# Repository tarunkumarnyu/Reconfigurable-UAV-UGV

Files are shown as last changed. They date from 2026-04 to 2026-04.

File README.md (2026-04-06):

# Reconfigurable UAV + UGV





> **Design project.** This repository documents the mechanical design, sizing, structural analysis, and electronics architecture of the vehicle. It is a CAD + analysis effort, not a software stack.

A hybrid robot that morphs between **quadrotor (UAV)** and **two-wheeled rover (UGV)** modes — inspired by the CalTech M4 Morphbot. The vehicle flies to a search location for rapid response, then transitions to ground mode in cluttered terrain to gain manoeuvrability and dramatically cut power consumption (dynamically stable → statically stable).

Targeted at search-and-rescue missions where pure ground robots get stuck and pure quadrotors burn through battery hovering.

## Demo

https://github.com/user-attachments/assets/98f587c6-136c-463c-a7f6-8aad75f0b5d4

## Configurations

<p align="center">
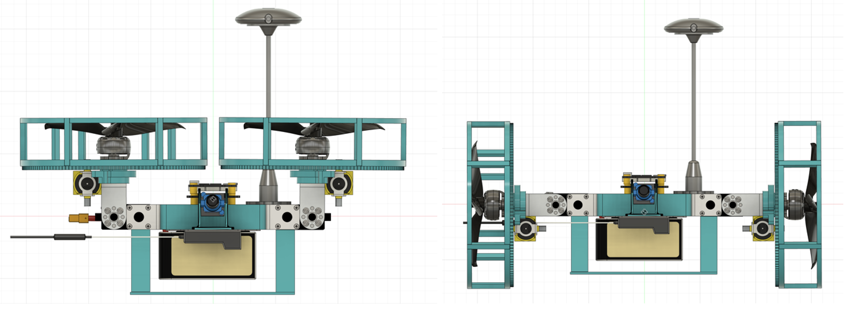
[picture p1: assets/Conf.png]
UAV and UGV configurations
  
</p>

| Mode | Actuators | When it's used |
|---|---|---|
| **UAV** | 4× BLDC motors | Long-distance traversal, gap-crossing, rapid deployment to a waypoint |
| **UGV** | 2× DC motors driving the wheels through a 1:10 gear ring | Cluttered indoor / collapsed-structure search where flight is unsafe or wasteful |
| **Reconfiguration** | 2× servos rotating the motor-arm assemblies | Switches between modes in place |

Total of **8 actuators**: 4 BLDC + 2 DC + 2 servos.

## Specifications

| | |
|---|---|
| Take-off weight | 1134 g |
| Thrust per motor | 340.2 g (≈1.2× hover thrust) |
| Power required | 31.08 Wh |
| Estimated endurance | 4.21 min (UAV mode) |
| Payload limit | 100 g |
| Length × height | 310 mm × 230 mm |
| Wheelbase (motor mount, diagonal) | 225 mm |
| Wheel diameter | 150 mm |
| Propeller clearance | 33 mm |
| Landing-gear height | 50 mm (15 mm ground clearance in UGV mode) |

<p align="center">
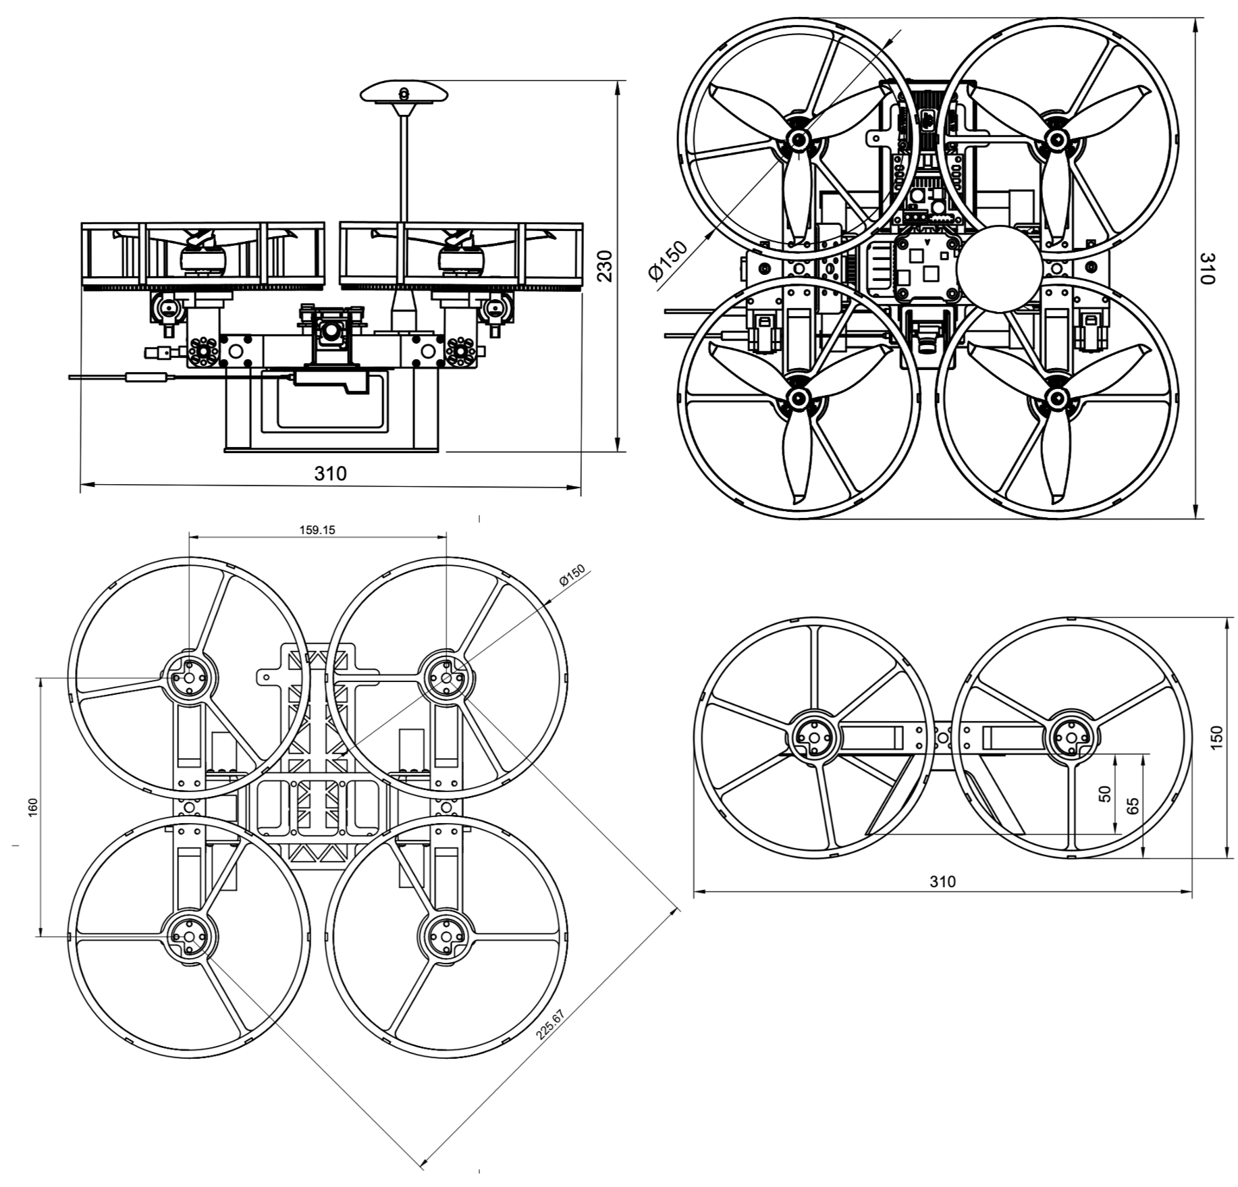
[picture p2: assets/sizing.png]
Dimensions and sizing
  
</p>

<p align="center">
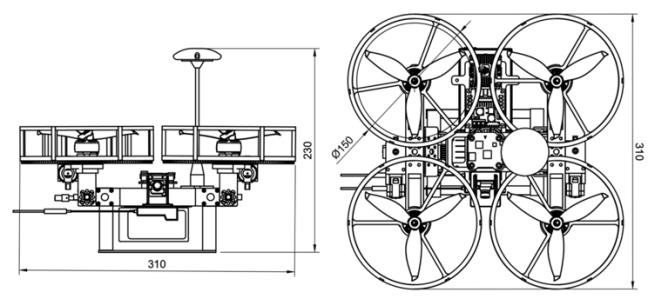
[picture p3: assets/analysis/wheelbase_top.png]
Top view — wheelbase and propeller clearance
  
</p>

## Sizing & Power Budget

The vehicle was sized from a target take-off weight, then back-solved through thrust, power, and endurance.

**Weight estimation.**

```
W_to = W_oe + W_pl + W_f
W_oe = 345 g (frame) + 630 g (electronics, no battery) = 975 g
W_f  = 225 g (battery, treated as fuel weight)
W_to = 975 + 225 = 1200 g
```

**Thrust estimation.** Hover requires thrust = weight; we add a 20 % margin for control authority.

```
T_required = 1.2 × 1200 g = 1440 g
T_per_motor = 1440 / 4 = 360 g
```

**Power estimation.** From a test-stand measurement at hover thrust per motor: 3.5 A @ 25.2 V → 88.2 W per motor.

```
P_motors = 4 × 88.2 W = 352.8 W
P_avionics ≈ 20 W
P_total ≈ 373 W
E_5min  = 373 W × (5/60) h = 31.08 Wh
```

**Battery selection.** A **6S 1300 mAh 150C LiPo** delivers 1.3 Ah × 25.2 V = **32.76 Wh**, leaving a small margin over the 31.08 Wh budget.

**Endurance** (capping discharge at 80 % to protect the LiPo):

```
P/W   = 373 / 1.2 ≈ 310.83 W/kg
I_avg = (1.2 × 310.83) / 25.2 ≈ 14.80 A
t     = (1.3 Ah × 0.8) / 14.80 A ≈ 0.0703 h ≈ 4.22 min
```

The 4.22 min UAV endurance is the **worst case** (continuous hover). UGV mode draws an order of magnitude less because the platform is statically stable on its wheels — this is the entire reason for the hybrid design.

## System Architecture

<p align="center">
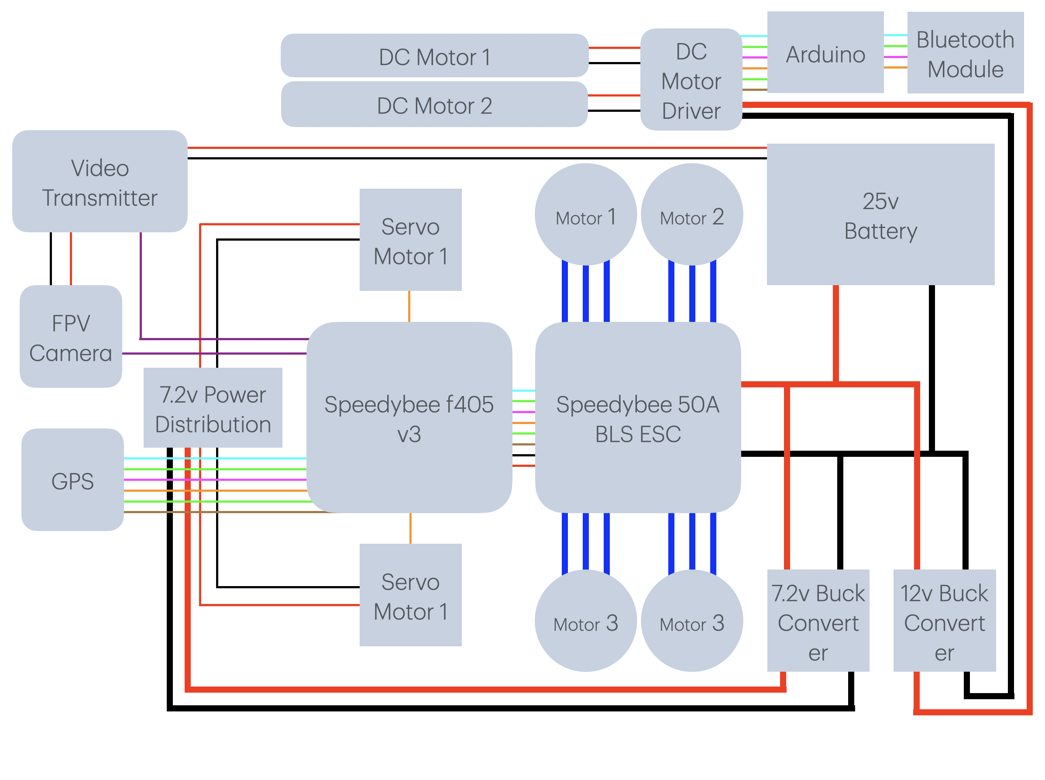
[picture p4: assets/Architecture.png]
Electrical / control architecture
  
</p>

**Flight controller.** STM32F405 ARM microcontroller with 6× UART for peripherals. Runs the UAV control loop and routes commands during reconfiguration.

**Ground controller.** Separate ATmega328-based board drives the H-bridge for the DC wheel motors in UGV mode — keeps the high-current ground drive isolated from the flight controller.

**Sensing.**
- **DPS310 barometer** — altitude hold.
- **Ublox NEO-M8N GPS** — 0.6–0.9 m position accuracy, on FC UART6 for waypoint navigation.
- **Compass** — heading reference for waypoint following, on I²C.
- **2.4 GHz SBUS receiver** — manual override, on UART2.

**FPV.** 1200 TVL 5 MP camera + 5.8 GHz video transmitter streaming live to the ground station's FPV display.

**ESCs.** 4-in-1 integrated 55 A ESC — single board for all four BLDC motors, total weight 15 g.

**Power tree.**
- 6S 1350 mAh Li-ion → 25.2 V → 4-in-1 ESC (BLDCs)
- LM2596S buck → 12 V → H-bridge → DC wheel motors
- XL4005 buck → 7.2 V @ 5 A → reconfiguration servos

## Structural Design

The frame has three structural sub-assemblies: **central body**, **motor-mount beams**, and **wheels**. Most parts are 3D printed in PLA+; the central chassis plate is **carbon fibre** for stiffness and weight.

**Central body.** Houses the flight controller, ATmega ground controller, ESCs, receiver, and battery. The battery sits at the geometric centre to keep CG aligned for both flight and ground modes.

**Motor-mount beams.** Run parallel to the central body on each side and pivot on the reconfiguration servos. They carry the BLDC motors in flight mode and become the rolling axle in ground mode. Mounting holes integrate a bearing seat to hold the wheel inner race.

<p align="center">
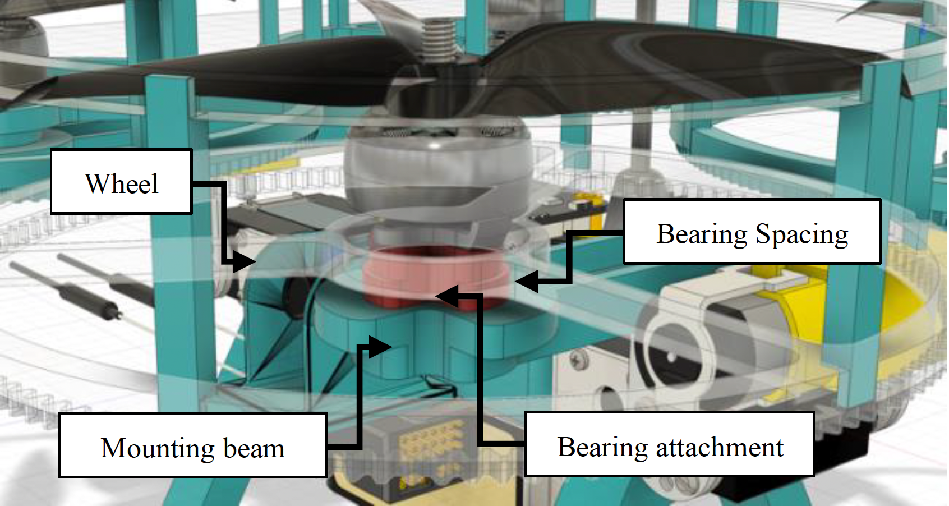
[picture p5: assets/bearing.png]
Bearing attachment detail
  
</p>

**Wheels.** Each wheel turns on a bearing to eliminate axle friction during ground motion. Both wheels are driven by a single DC motor through a common ring gear, so the wheels themselves are printed with **integrated gear teeth on the outer circumference** giving a **1:10 gear ratio** — high torque for climbing obstacles, in trade for top speed. The wheel webs are **topology-optimised** to remove material while preserving stiffness, also reducing aerodynamic drag in flight mode.

<p align="center">
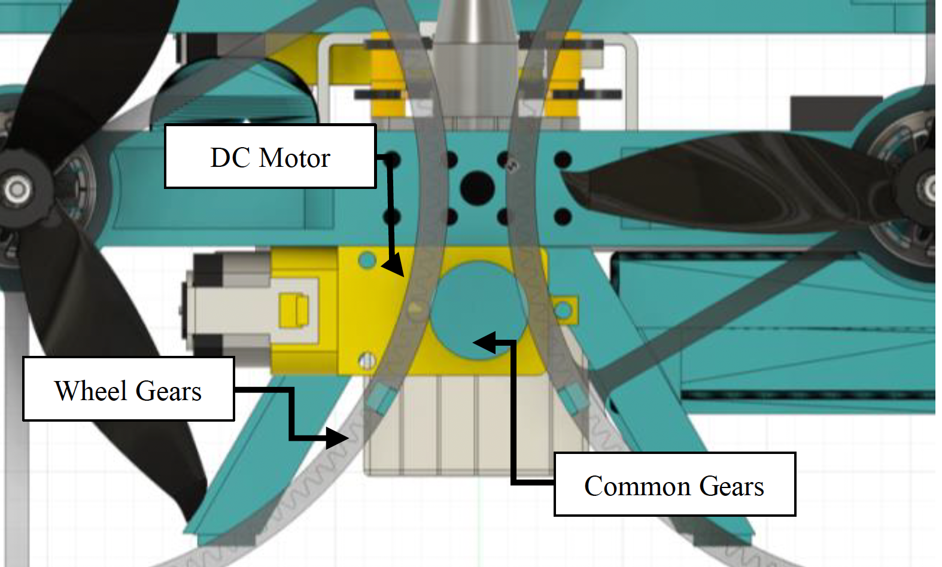
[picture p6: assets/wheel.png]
Wheel with integrated gear teeth
  
  &nbsp;
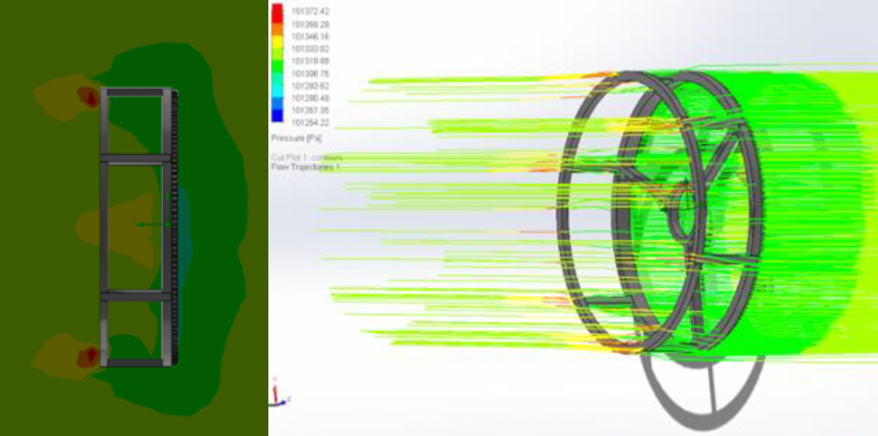
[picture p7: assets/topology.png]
Topology optimisation result
  
</p>

<p align="center">
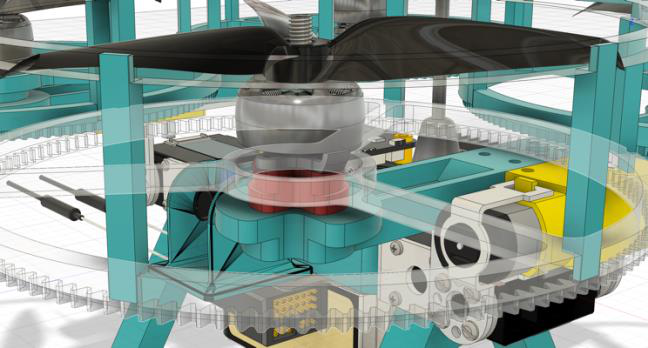
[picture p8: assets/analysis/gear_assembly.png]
Wheel gears, DC motor, common gear assembly
  
</p>

## Centre of Gravity

The CG is held close to the geometric centre of the frame by anchoring the battery (the heaviest single item) to the bottom of the central body. There is a deliberate **CG shift between modes**:

- **UAV mode** — CG is ~5 mm above the top of the central structure.
- **UGV mode** — CG is ~2 mm above the bottom of the central structure.

The two CG positions differ by ~23 mm (20 mm of which is the central plate thickness). In flight that puts the CG slightly *above* the rotor plane for predictable handling; on the ground it sits *below* the wheel axles, giving a low static stability margin against tipping.

<p align="center">
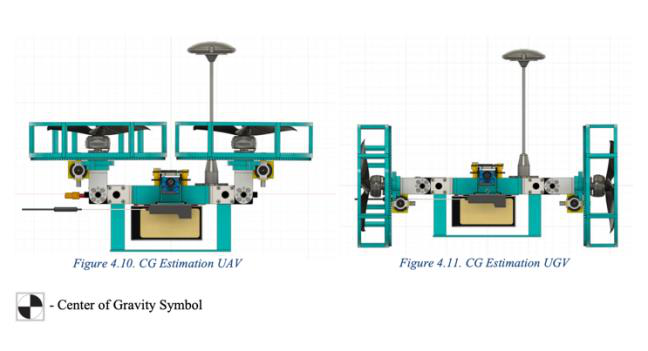
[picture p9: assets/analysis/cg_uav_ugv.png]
CG estimation in UAV and UGV modes
  
</p>

## Structural Analysis (FEA)

Static structural analysis was run in **Autodesk Fusion 360 Simulation** on the load-bearing parts. Loads are taken from worst-case flight forces (per-motor thrust + dynamic factor).

**Motor-arm beam.** Fixed at the centre (servo mount) with **20 N applied at each BLDC mounting hole**. Maximum von Mises stress is **5.742 MPa**, located between the servo and the BLDC mount — the expected stress concentration where the arm transitions from the servo coupling to the motor cantilever.

<p align="center">
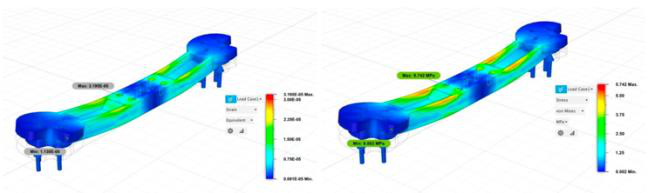
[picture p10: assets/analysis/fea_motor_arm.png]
Motor arm beam FEA — max 5.742 MPa
  
</p>

**Central structure (servo rear mount).** Fixed at the flight-controller mounting holes with **40 N per side** at the servo mounting holes (each side carries two BLDC motors at 20 N each). Maximum stress is **0.5 MPa** — a very high factor of safety, deliberately so since this part holds the entire reconfiguration mechanism.

<p align="center">
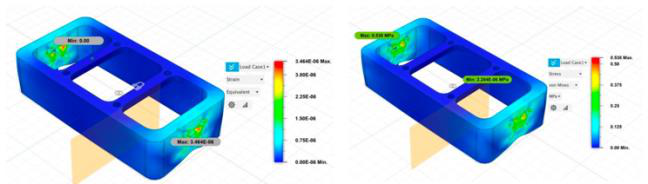
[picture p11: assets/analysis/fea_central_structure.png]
Central structure FEA — max 0.5 MPa
  
</p>

**Landing gear.** Skid type, chosen for stability and ground-contact area. Topology-optimised under landing-load constraints to maximise strength-to-weight. Maximum stress in the optimised geometry is **0.6 MPa**.

<p align="center">
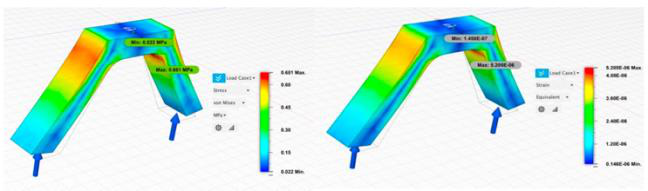
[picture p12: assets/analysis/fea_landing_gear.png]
Landing gear FEA — max 0.6 MPa
  
</p>

The landing-gear height (50 mm) is also constrained to be **smaller than the outer wheel radius**, so it never touches the ground in UGV mode — a 15 mm clearance is maintained throughout ground motion.

## Aerodynamics — Wheel Drag

Because the wheels stay on the airframe in UAV mode, their cross-section adds parasitic drag. Streamline analysis on the topology-optimised wheel shows the gear-tooth ring acts as a (mild) bluff body but the open spoke pattern lets most of the flow through, which was the goal of the optimisation:

<p align="center">
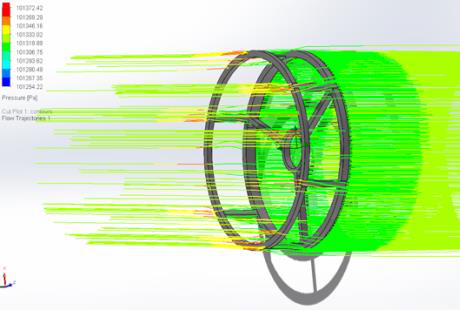
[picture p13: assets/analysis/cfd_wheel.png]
Streamline visualisation over the wheel
  
</p>

## Why a hybrid platform

A pure quadrotor wastes energy hovering and is unsafe near survivors and rubble. A pure ground robot can't cross gaps, climb collapsed slabs, or be deployed quickly across a wide search area. The reconfigurable approach uses each mode where it's actually efficient:

- **Fly** to the search zone — fast, terrain-independent.
- **Drive** inside the zone — orders-of-magnitude longer endurance, safer around people, and the static-stability margin means the vehicle can sit still without burning power.

## Status

Built, flown, and ground-driven. Reconfiguration is mechanical (servo-driven), GPS waypoint navigation works in UAV mode, and the FPV link feeds the ground station for manual operation in either mode.

## Credits

Concept inspired by the CalTech **M4 Morphbot**. Mechanical design, electronics integration, and bring-up by Tarunkumar Palanivelan.

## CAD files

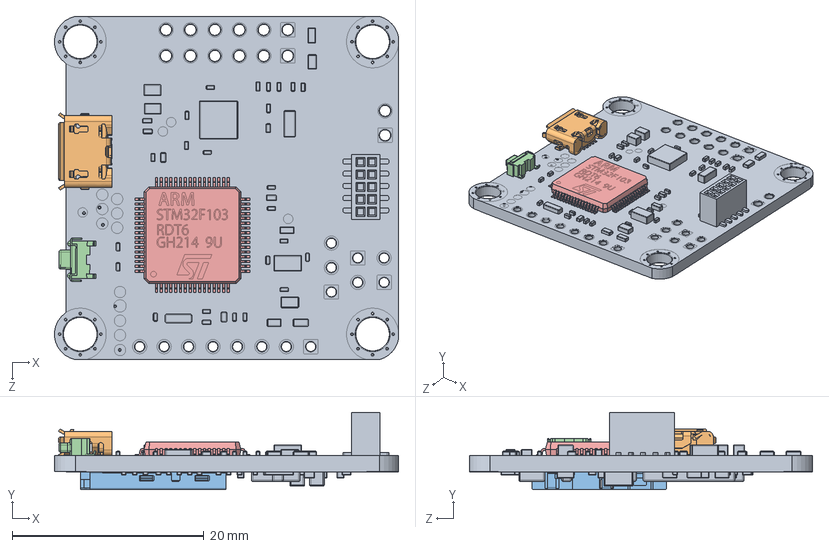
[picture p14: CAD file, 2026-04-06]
cad/Hobbywing Xrotor F4 FC.SLDASM
35.9 x 8.05 x 35.8 mm
MOTHER BOARD
USB port
microSD slot
Tact SMD Corner SWITRONIC IT-1100
STM32F103RDT6

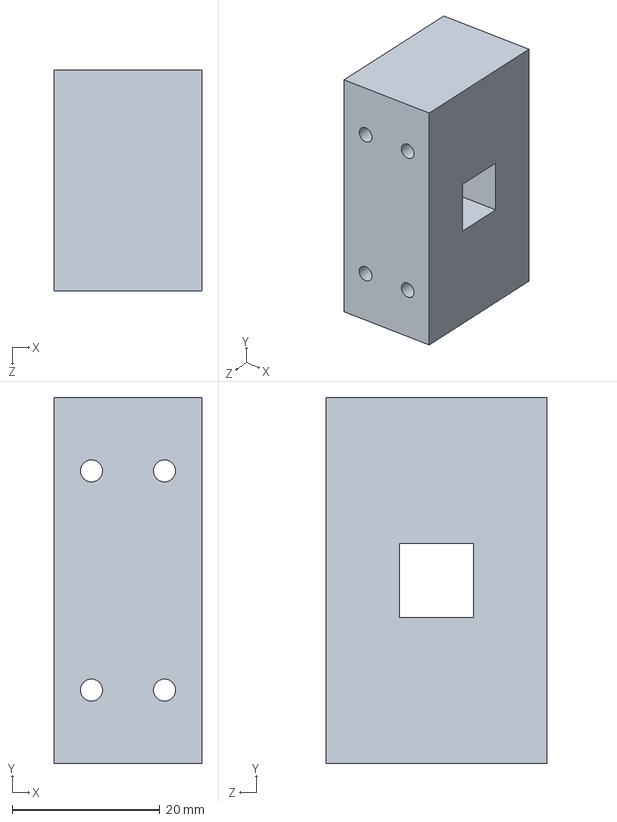
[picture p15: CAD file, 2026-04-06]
cad/Spacer_Block.SLDPRT
20.0 x 49.6 x 30.0 mm

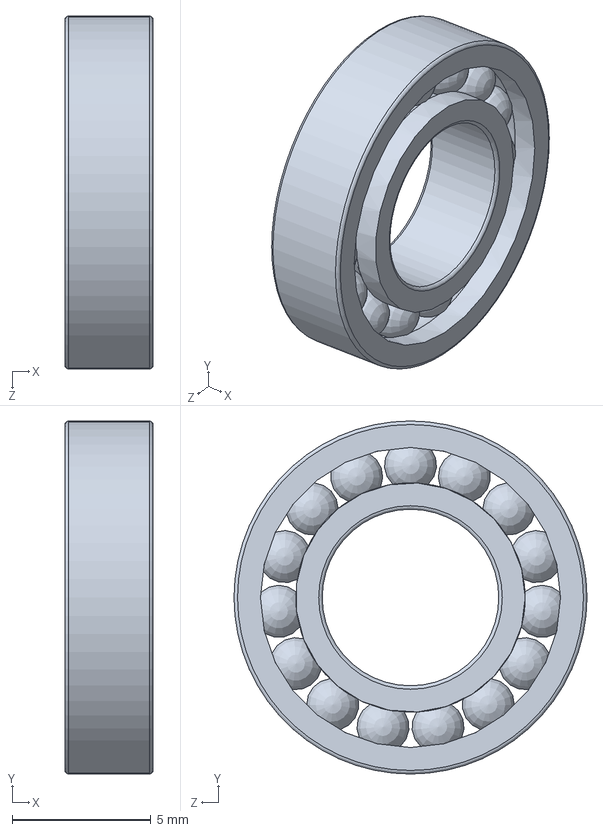
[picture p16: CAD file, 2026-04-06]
cad/instrument ball bearing_68_am.sldprt
3.17 x 12.7 x 12.7 mm

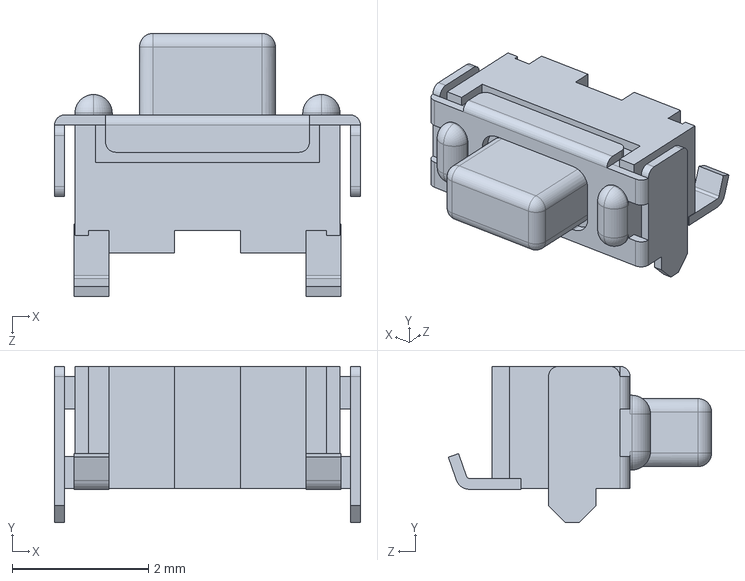
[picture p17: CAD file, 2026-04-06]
cad/Tact SMD Corner SWITRONIC IT-1100.SLDPRT
4.50 x 2.30 x 3.87 mm

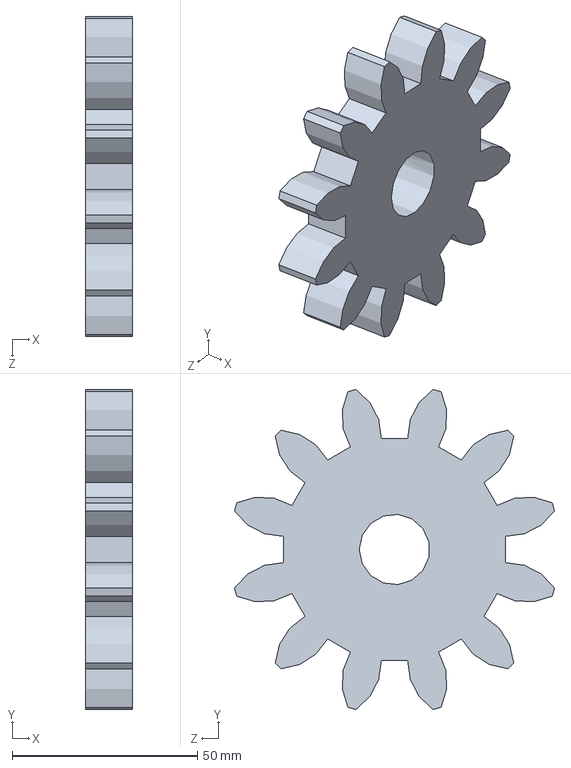
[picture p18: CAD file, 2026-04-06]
cad/spur gear wheel.SLDPRT
12.7 x 86.4 x 86.4 mm

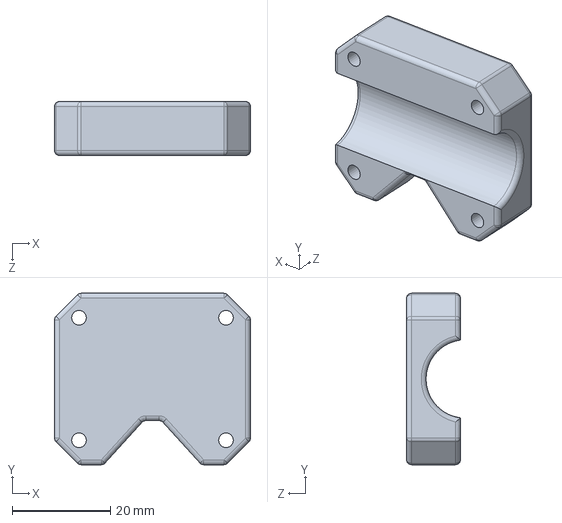
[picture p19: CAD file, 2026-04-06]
cad/bo_mountv3back.SLDPRT
40.0 x 35.0 x 11.0 mm

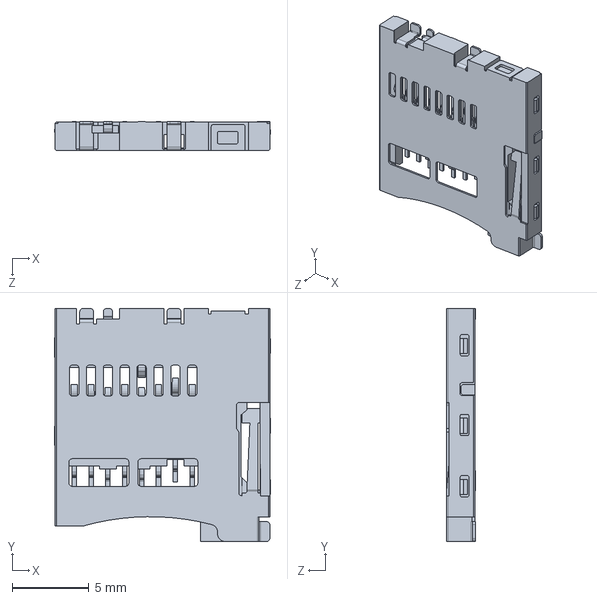
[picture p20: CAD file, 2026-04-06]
cad/microSD slot.SLDPRT
14.1 x 15.2 x 1.88 mm

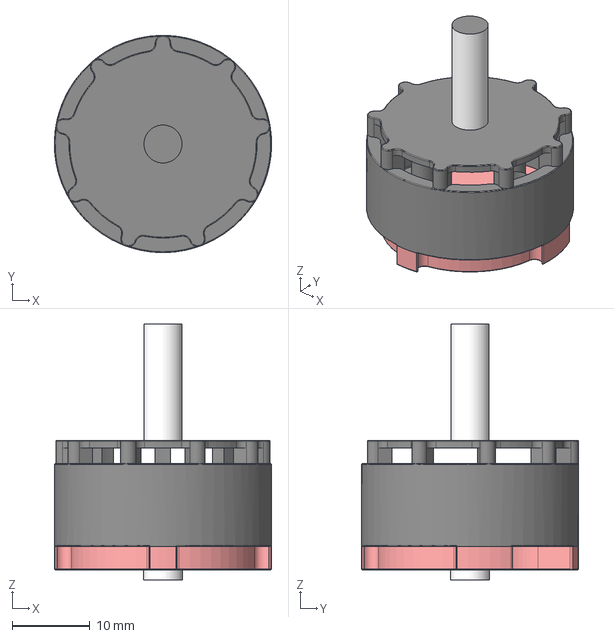
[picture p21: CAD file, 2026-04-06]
cad/Emax Rs2205 v1.step
28.0 x 28.0 x 33.0 mm

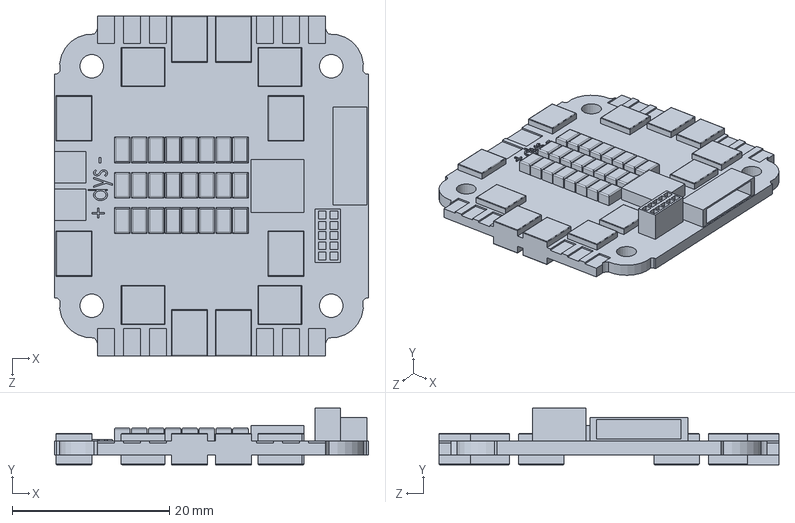
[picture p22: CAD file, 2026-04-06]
cad/DYSf30A_4in1_ESC_Coloured.SLDPRT
40.0 x 7.20 x 43.3 mm

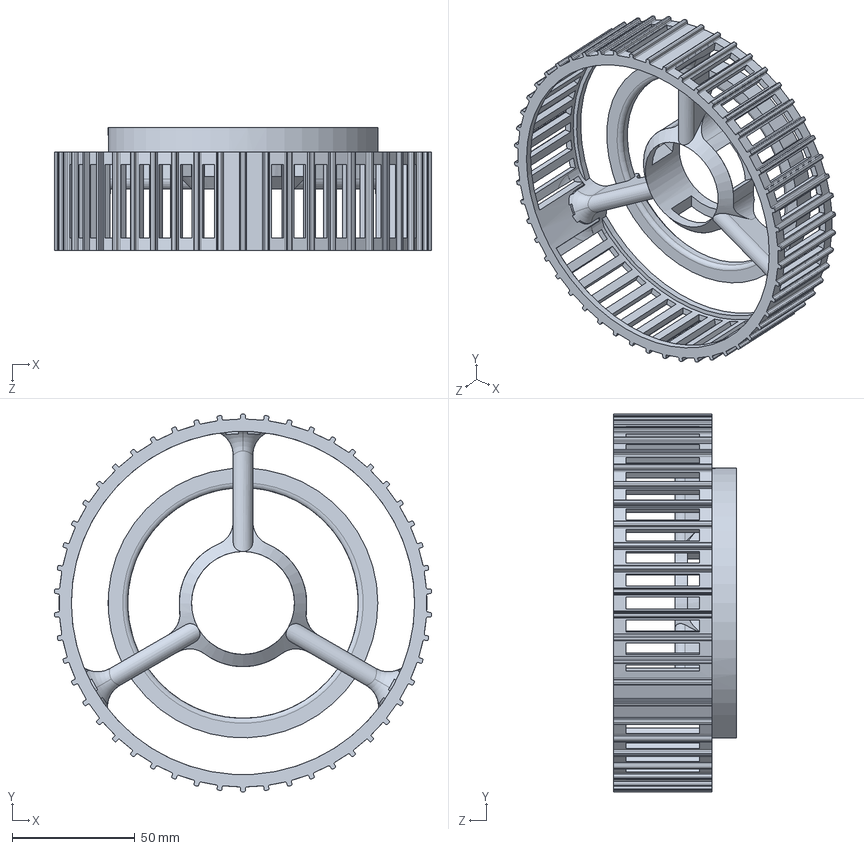
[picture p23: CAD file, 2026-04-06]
cad/wheel.SLDPRT
153.8 x 154.0 x 50.0 mm

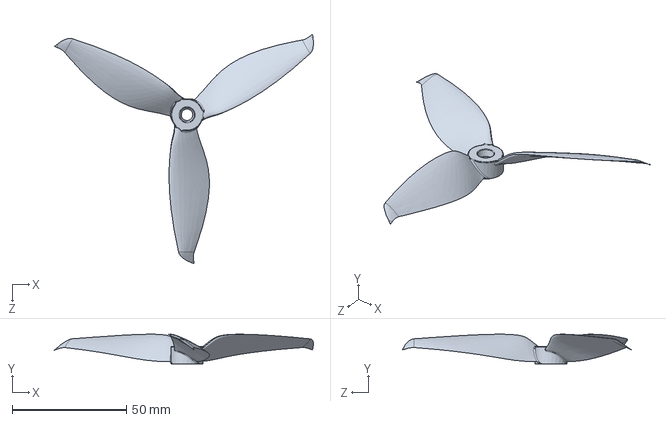
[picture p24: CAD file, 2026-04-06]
cad/GEMFAN_5152_CW.SLDPRT
113.3 x 12.9 x 100.5 mm

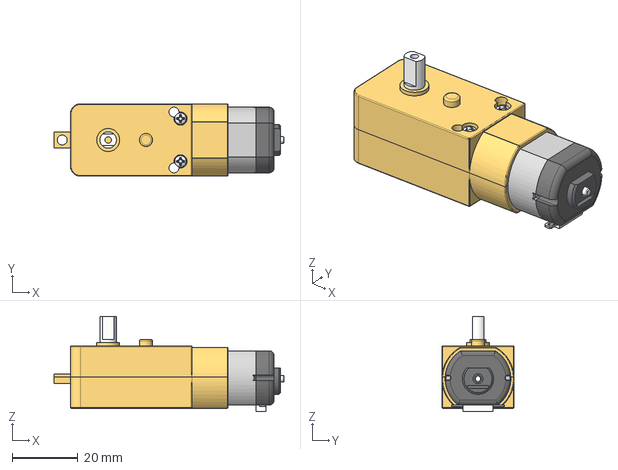
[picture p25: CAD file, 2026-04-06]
cad/One side TT Motor v1.step
70.0 x 22.0 x 29.0 mm

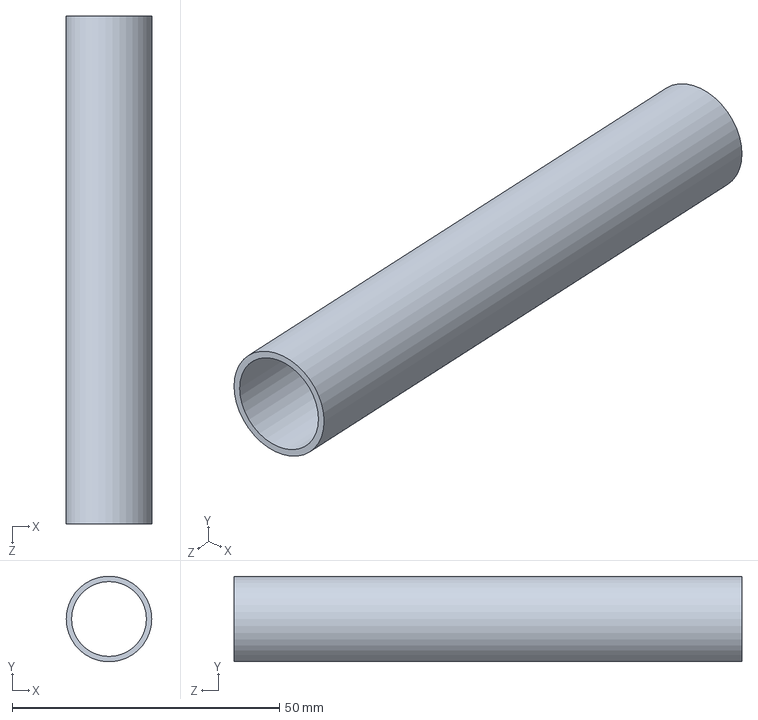
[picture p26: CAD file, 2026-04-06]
cad/95rod.SLDPRT
16.0 x 15.9 x 95.0 mm

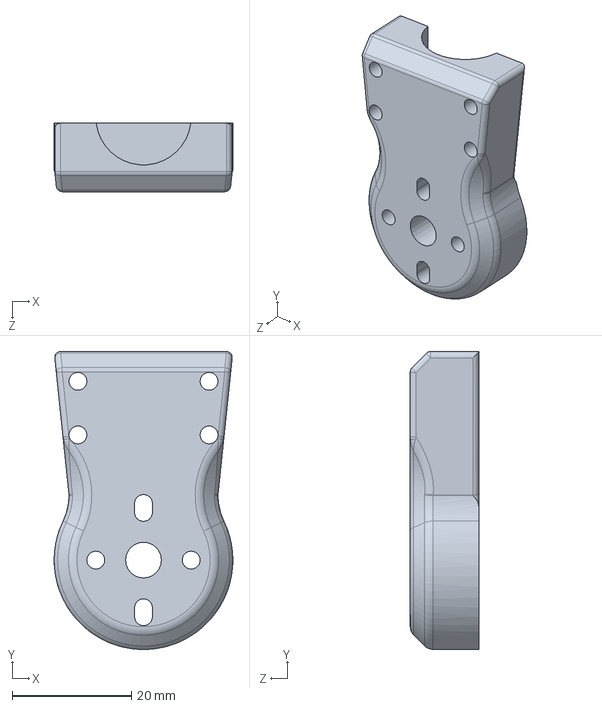
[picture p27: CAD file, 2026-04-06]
cad/mmbot.SLDPRT
30.0 x 50.0 x 11.5 mm

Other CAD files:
cad/rds3120-3d.SLDASM
cad/ANSI B18.6.5M - 2,2 x 0,8 x 4 - B - I.SLDPRT
cad/GE_57.SLDPRT
cad/DUOPAN-SG.SLDPRT
cad/103rod.SLDPRT
cad/240rod.SLDPRT
cad/AS 1427 - M2,5 x 4.SLDPRT
cad/DUOPAN-DG.SLDPRT
cad/Ljoint.SLDPRT
cad/Servo_Attach.SLDPRT
cad/Spacer_Block Top.SLDPRT
cad/USB port.SLDPRT
cad/ZJ-DUAN.SLDPRT
cad/bo_mountv3.SLDPRT
cad/corpo_3ds3120.SLDPRT
cad/mmtop.SLDPRT
cad/prevailing torque hex flange 2.SLDPRT
cad/prevailing torque hex nut_am2.SLDPRT
cad/socket head cap screw_am2.SLDPRT
cad/spur gear_am2.SLDPRT

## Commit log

2026-04-06 docs: add full project README with architecture, specs, and demo
    Replace the one-line README with a complete writeup covering both
    UAV and UGV modes, the electrical/power architecture, the mechanical
    design (frame, bearing mount, geared wheel), and a compressed demo
    video. Images sourced from the portfolio site.
2026-04-06 docs: add sizing math, FEA, CG analysis, and CFD figures
    Pull weight/thrust/power/endurance derivations, Fusion 360 static
    structural analyses (motor arm, central structure, landing gear),
    CG estimation, and wheel CFD from the project's IEEE technical
    report.
2026-04-06 Replace demo video link with user-attachments link
    Updated demo video link in README.
2026-04-06 Add reconfigurable UAV-UGV CAD files — SolidWorks parts and assemblies
    [103rod.SLDPRT, 240rod.SLDPRT, 95rod.SLDPRT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]
